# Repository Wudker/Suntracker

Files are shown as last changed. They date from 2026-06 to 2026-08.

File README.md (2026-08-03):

# Suntracker – Solar-Tracking Powerbank with MPPT

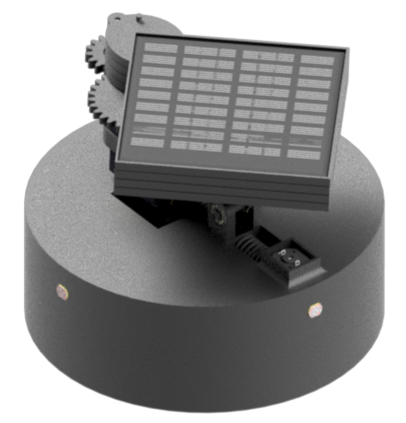
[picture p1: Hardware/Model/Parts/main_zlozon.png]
Suntracker CAD model


Suntracker is a design-stage solar-tracking powerbank developed as a mechatronic student project. It combines dual-axis panel positioning, Li-Ion battery charging, powerbank functionality and a simplified P&O-based MPPT concept. Photoresistors guide the automatic search for the optimal panel position, while the INA219 monitors photovoltaic voltage and current. An STM32 microcontroller controls the positioning mechanism, power rails and charging current through a digital potentiometer. The repository contains firmware, PCB and mechanical files, simulations, a BOM, documentation and validation calculations.

## Technologies

`STM32L051C8` `C/C++` `Photovoltaics` `P&O MPPT` `INA219` `MCP40xx` `TP4056` `XL4015` `DRV8833` `Li-Ion battery` `KiCad` `LTspice` `3D printing`

## Usage and development status

After assembling the device, program the microcontroller using an ST-Link and verify the battery polarity, charging current and mechanical movement limits before operation. The controller searches for the strongest light direction, positions the panel and adjusts the charging current according to the measured photovoltaic power. The project is currently a complete design and documentation package supported by approximate mechanical and energy calculations. The next step is to build a physical prototype and verify tracking efficiency, energy balance and long-term outdoor reliability.

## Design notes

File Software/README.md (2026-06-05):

You need to use ST-Link in order to programm device.

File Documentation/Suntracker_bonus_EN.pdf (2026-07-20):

Suntracker – Instructions | Project Documentation Appendix

## Suntracker

User Manual and Commissioning/Service Instructions

Author: | Bartłomiej Dusza
Student ID: | 274546
Date: | June 17, 2026
Status: | short appendix to the project documentation

This document supplements the project documentation with two missing sections: the user manual and the commissioning/service instructions. It does not replace the main documentation, schematics, PCB files, source code, BOM, simulations or test results.

### 1 Scope and Intended Use

Suntracker is a prototype autonomous solar tracker with a solar powerbank function and a simplified MPPT algorithm. The device positions the panel toward more favorable lighting, measures panel parameters, controls the actuators and reduces energy consumption by entering sleep mode.
The prototype is intended for educational and validation purposes. It is not a finished device designed for long-term, unattended outdoor operation and is not protected against moisture.

### 2 User Manual

### 2.1 Safety Rules

- Do not operate the prototype in rain, at high humidity or on a conductive surface.
- Do not touch the mechanism while the motors are moving, and do not block the panel by hand.
- Do not use the system if the cell is swollen, hot, mechanically damaged or has damaged insulation.
- Do not short-circuit the cell output, panels, 5 V line or 3.3 V line.
- Perform the first powerbank function tests with a test load, not an expensive device.

### 2.2 Preparation for Operation

1. Place the device on a stable surface with enough space for the panel to move freely.
2. Make sure that the wires do not enter the working area of the arm, lead screw or servo.
3. Point the panel toward the light or place a light source in front of the device.
4. Before connecting a USB load, use a multimeter to verify that the output voltage is approximately 5 V.

### 2.3 Startup and Normal Operation

1. Press the POWER_ON power/wake-up button.
2. After startup, the system should activate the required power sections and begin the panel unfolding or positioning sequence.
3. In Harvest_update mode, the device searches for a more favorable panel position using the photoresistors and power measurement.
4. In Harvest mode, the system keeps the panel in its operating position and performs MPPT adjustments.
5. Under low-light conditions, the system may limit movement and enter a power-saving mode.

Correct operation means short, controlled movements of the mechanism, no microcontroller resets, and no noticeable heating of the wires, drivers or converters.

### 2.4 Shutdown, Folding and Storage

1. Press the power button.
2. Wait for the mechanism to complete the folding movement.
3. Do not disconnect the cell while the motors are moving unless an emergency occurs.

### 2.5 Emergency Conditions

Stop the test immediately if smoke, the smell of overheated electronics, excessive cell heating, continuous system resets, a blocked mechanism, sparking, or a significant deviation of the 5 V or 3.3 V rail from its nominal value occurs.

1/2

Suntracker – Instructions | Project Documentation Appendix

### 3 Commissioning and Service Instructions

### 3.1 Required Tools

Multimeter | checking for short circuits, polarity, and the 3.3 V, 5 V, cell and panel voltages.
Laboratory power sup- ply | first power-up with current limiting.
ST-Link / SWD | programming the STM32L0 microcontroller.
Computer with an IDE | compiling and uploading the source code.
Lamp / light source | testing the photoresistors and tracking algorithm.
Test load | testing the 5 V output and powerbank function.

### 3.2 Inspection Before First Power-Up

1. Compare the assembled PCB with the BOM and schematic.
2. Check the polarity of the cell, panels, diodes and electrolytic capacitors.
3. Measure the resistance between VBAT–GND, 5V–GND, 3V3–GND and PANEL+–PANEL-. There should be no short circuit.
4. Check that the mechanism moves freely within its intended range.
5. Check for collisions between PCB components and the motor, lead screw, servo and arm.

### 3.3 First Electronics Startup

1. Disconnect the motors, servo and USB load.
2. Connect power using a laboratory power supply with current limiting, or use a tested 1S cell.
3. Check the stability of the 3.3 V rail. Then check the 5 V rail if it is active.
4. Check that the microcontroller is not resetting repeatedly.
5. Use a debugger to verify I2C communication with the INA219 and MCP40xx devices.

### 3.4 Microcontroller Programming

1. Connect GND, SWDIO, SWCLK and, optionally, NRST from the ST-Link programmer.
2. Select the board/microcontroller variant that matches the STM32L0 used in the device.
3. Make sure that the environment contains the required libraries: STM32, Wire/I2C, timers, STM32LowPower, STM32RTC, INA219 and MCP40xx.
4. Compile and upload the firmware. After uploading, reset the system and check its response to the POWER_ON button.

### 3.5 Actuator and Sensor Startup

Connect the actuators in stages. First test one DC motor in both directions, then the second motor, followed by the servo over a limited range. If the direction of movement is opposite to the expected direction, swap the motor wires or reverse the logic in the control function.
Test the photoresistors under uniform illumination and by covering the sensors one at a time. Illuminating one side should change the indicated direction. If the directions are shifted, correct the pin mapping or the description of the sensor orientation.

### 3.6 MPPT and Sleep Mode Test

For the MPPT test, check the voltage and current readings from the INA219 and the system response to changes in illumination or load. Changing the MCP40xx setting should affect the operating conditions of the charging circuit. If the algorithm oscillates too much, reduce the adjustment step or increase the measurement settling time.
For sleep mode, confirm that the System_Sleep() function switches off unnecessary power sections, places the H-bridge inputs in a safe state and allows the system to wake using the button. After changes to interrupt handling, perform several cycles: startup – operation – sleep – wake-up.

2/2

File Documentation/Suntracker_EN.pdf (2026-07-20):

# Suntracker Project

Final Documentation of a Theoretical Project

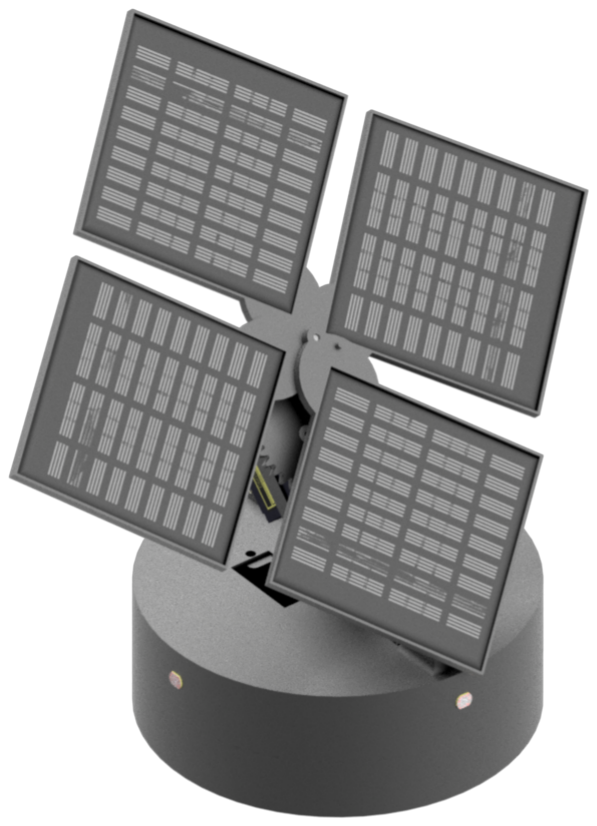
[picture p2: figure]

Author | Bartłomiej Dusza, Eng.
Date | June 17, 2026
Supervisor | Krzysztof Kwoka, Ph.D., Eng.

This document summarizes the project completed for the “Electronic Systems in Mechatronics” course.

# Contents

1 Project Objective and Assumptions | 2
2 Electronics | 3
3 Mechanical Design | 13
4 Software | 18
5 Validation | 21
6 Final Conclusions | 30
7 References | 32

# 1 Project Objective and Assumptions

The objective of the project is to design a prototype energy storage system powered by photovoltaic panels. The device is intended to operate as a small autonomous energy source capable of charging a Li-Ion cell and powering a load through a 5 V section. Unlike simple fixed solar systems, the proposed device includes a mechanism that positions the panels relative to the direction of incoming light. This solution is intended to extend the effective exposure time of the panels and increase the amount of energy that can be harvested during the day.

Existing solutions of this type can be divided into several groups. The simplest photovoltaic systems use panels mounted at a fixed angle. Such a solution is inexpensive, simple and reliable, but it cannot actively adjust the panel position to the current position of the sun. More advanced designs use single-axis or dual-axis solar trackers that change the panel position during operation. Single-axis trackers most often follow the sun from east to west, while dual-axis trackers also allow the tilt angle to be corrected. This can increase the potential energy yield, but it also makes the mechanical design and control electronics more complex and worsens the energy balance because the actuators require power.

The proposed prototype uses an intermediate approach. Its purpose is not to maximize power at any cost, but to evaluate whether a small self-sufficient solar system is practical. The key assumption is a positive energy balance: the energy used for control, measurements and panel positioning should be lower than the additional energy obtained through improved panel positioning. For this reason, the system should operate periodically, remain in a low-power mode most of the time, and activate the actuators only when the panel position must be changed.

The design uses four small photovoltaic panels connected in series, a panel voltage and current measurement circuit, a DC/DC converter, a cell charging and protection circuit, and a microcontroller supervising the complete system. The system should measure the current power generated by the panels, adjust the operating point using a simplified pseudo-MPPT algorithm, and control the actuators responsible for positioning the structure. Safe charging of the Li-Ion cell and disconnection of actuators when they are not required are also important design requirements.

The scope of the project includes creating a prototype model, designing the power and control paths, preparing a mechanical structure that allows the panel position to be changed, and developing basic control software. The project is theoretical in nature.

# 2 Electronics

The system block diagram presents the general structure of the device’s power, measurement and control paths. The photovoltaic panels are the energy source, and their voltage and current are measured to determine the current power supplied by the system. The energy is then transferred to the DC/DC converter and the BMS section responsible for charging and protecting the cell, which acts as the energy storage device. Separate voltage sections are supplied from the cell: 3.3 V for the logic and 5 V for the actuators, mainly the motors. The microcontroller is the central control unit. Based on the measured data, it supervises the pseudo-MPPT operation and controls the H-bridge responsible for positioning the panels.

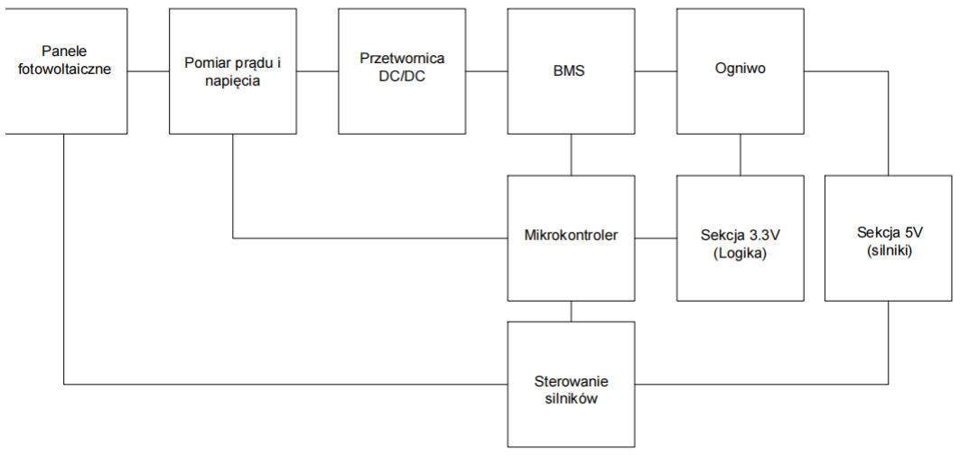
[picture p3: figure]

Figure 2.1: System block diagram.

## 2.1 Photovoltaic Panels

The power source is one of the most important parts of the system. Photovoltaic panels are nonlinear power sources that use the internal photoelectric effect. Because of this nonlinear behavior, maximum power point tracking (MPPT) is required to obtain the highest possible power. The main idea is to select the current drawn from the panel so that the system receives the maximum available power.

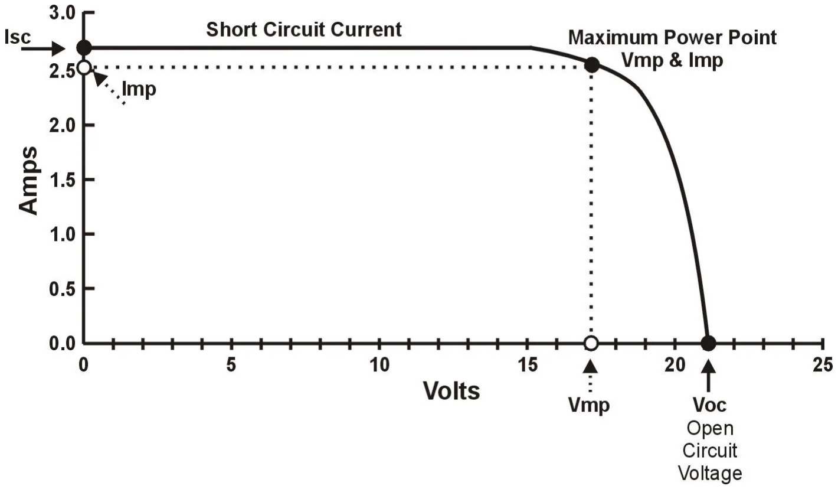
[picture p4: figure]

Figure 2.2: Panel current as a function of voltage [1].

Control of such a panel is based on reading its current voltage and current and then driving the DC/DC converter connected to the panel input. Photovoltaic panels can be connected in series to add their voltages, in parallel to add their currents, or in a mixed configuration. The project uses four identical panels, each with a nominal voltage of 5.5 V and a power rating of 0.4 W, connected in series. This configuration was selected to reduce transmission losses caused by the resistance of the wires. When connected in series, the panels provide a nominal voltage of approximately 22 V and a total power of 1.6 W. This provides enough voltage margin for the converter to operate under lower light levels. The disadvantage of this configuration is its sensitivity to differences in illumination between individual panels. If one panel is poorly illuminated, it may significantly limit the entire string. An alternative solution would be to connect two panels in series as one pair and then connect two such pairs in parallel, producing approximately 11 V at the output. The disadvantage is that current may flow from the better-illuminated pair to the less-illuminated pair. Schottky diodes can prevent this reverse current, but they introduce a voltage drop and additional power losses. With a series connection, bypass diodes may also be connected in parallel with the individual panels. They allow current to bypass a shaded panel or one that temporarily produces much less power than the others. As a result, one poorly illuminated panel does not block the complete string, although the total voltage is reduced. This improves resistance to partial shading, but increases the component count and introduces additional diode losses. All four panels could also be connected in parallel. In this case, the output voltage would remain approximately 5.5 V, while the nominal current would increase to approximately 0.29 A and the total power would remain approximately 1.6 W. This configuration would be more resistant to partial shading of one panel. However, such a low voltage would make it difficult to use a step-down converter and would most likely require a step-up converter. In practice, this option would be less suitable for the selected power architecture because it would produce higher wire currents and greater conduction losses.

## 2.2 Power Conversion

This section is divided into the converter used to implement pseudo-MPPT and the converters that generate the voltage rails required by the individual components from the battery voltage.

The converter section can be implemented in three main ways. The first is a custom discrete converter built from basic power-electronic components such as an inductor, diode, MOSFET and control circuit. The second approach is to use a ready-made DC/DC converter controller. The third option is a more highly integrated circuit that controls the converter and also provides additional functions such as MPPT and cell charging control.

For the proposed system, the main selection criteria were implementation complexity, ease of commissioning under prototype conditions, availability of documentation, and suitability for a photovoltaic-powered device. Table 2.1 compares the considered options.

Table 2.1: Comparison of converter section implementations

Solution | Advantages | Limitations | Assessment
Custom discrete converter | Very high design flexi-bility, component selec-tion matched precisely to system requirements, and potentially high effi-ciency. | Highest design com-plexity, including the need to solve control, feedback, stability and power-component se-lection issues. | The most flexible solution, but too complex for the pro-totype stage
XL4015 [2] | Simpler implementa-tion, sufficient voltage and current ratings, and basic built-in pro-tection mechanisms. | Less flexible than a dis-crete solution and no native MPPT function. | The most practical choice for the pro-totype
BQ25750 [3, 4] | High level of integration, MPPT support and Li-Ion cell charging func-tions. | Greater application complexity, more dif-ficult implementation and stricter require-ments for the design of the complete power section. | The most function-ally advanced solu-tion

Considering the prototype nature of the device and the need to limit system complexity, the XL4015 was selected as the most reasonable solution [2]. Compared with the BQ25750, it is easier to implement and commission while providing sufficient parameters for the proposed system. However, the XL4015 does not provide native MPPT. This function must therefore be implemented externally, and the required cell charging profile must be handled separately.

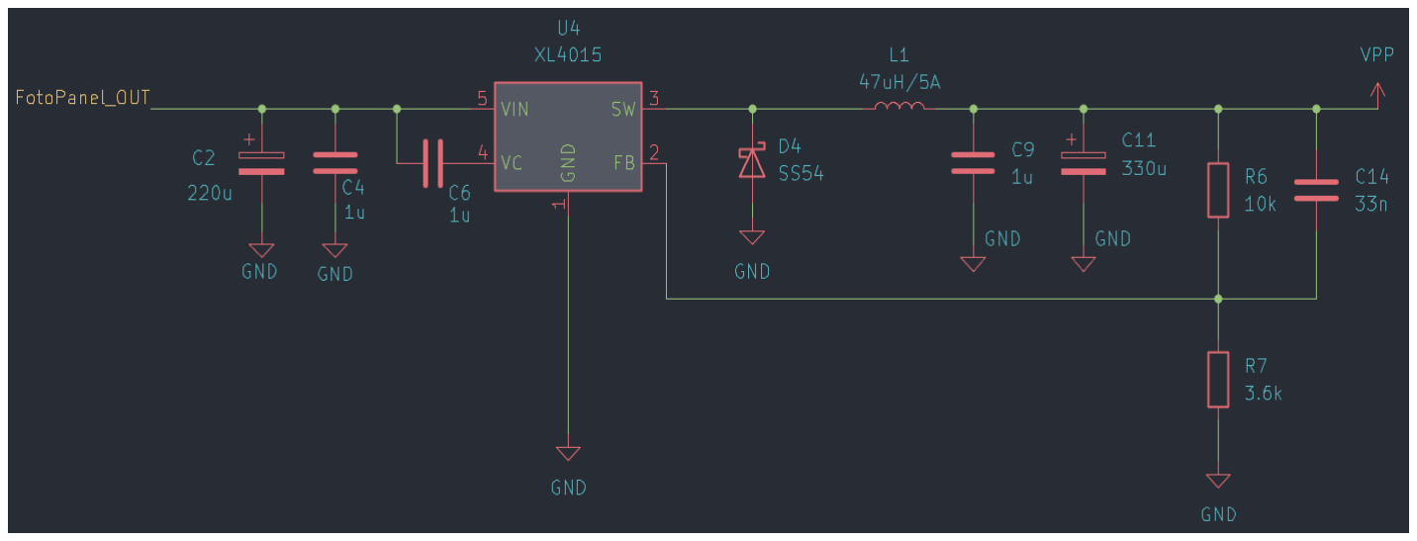
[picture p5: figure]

Figure 2.3: Converter circuit diagram.

The second section contains two converters: one supplies the 3.3 V rail and the other supplies the 5 V rail. The 3.3 V section uses the MCP1825S33. Its low dropout voltage is an important parameter because the regulator is powered directly from the battery. A power-path circuit is also used to switch the supply of this section automatically between the battery and the panels.

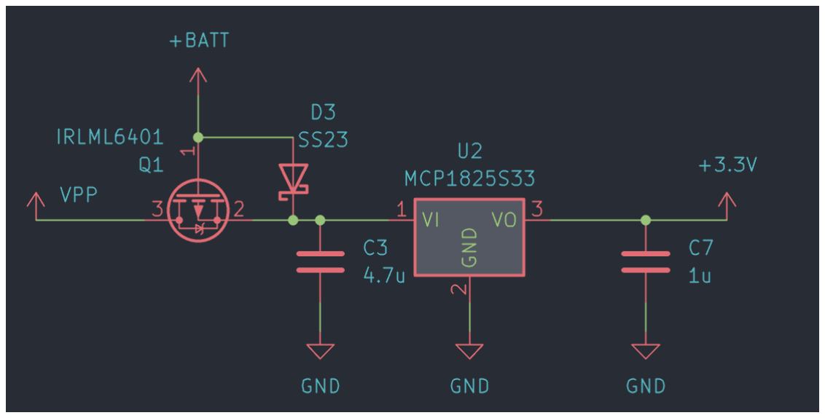
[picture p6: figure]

Figure 2.4: 3.3 V converter circuit diagram.

The second converter is based on the TPS61022, for which a low input voltage is also an important parameter. Another visible difference is the large number of capacitors. Their placement follows both the manufacturer’s documentation and the needs of the system, because this section mainly powers the motors and supplies the device connected to the USB output. The capacitors are required because the DC motors and servos draw high currents during operation and introduce significant noise into these power lines.

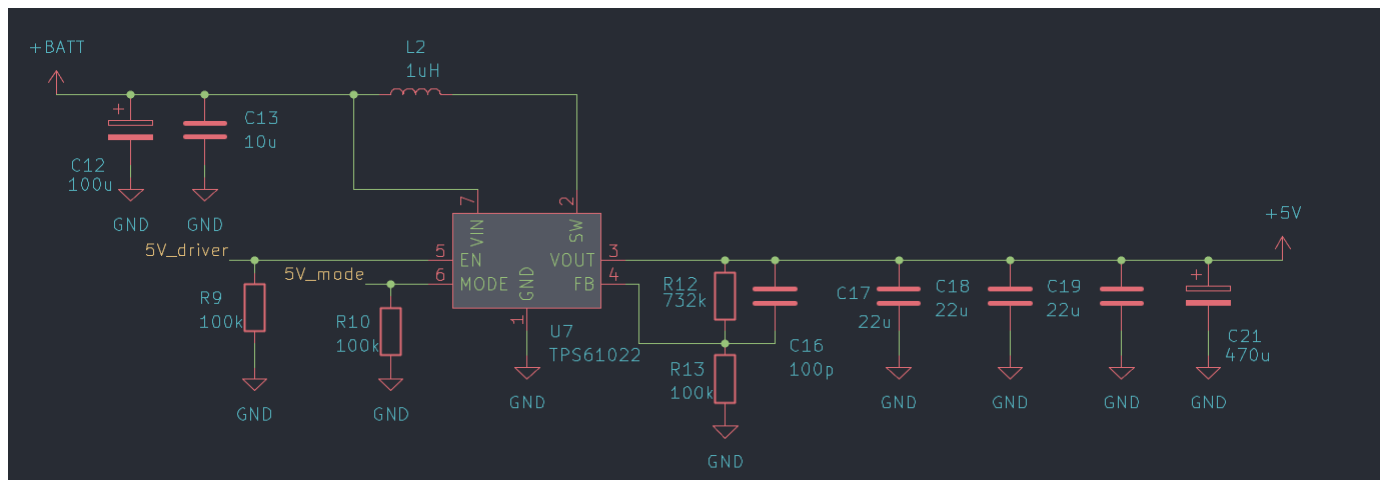
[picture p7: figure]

Figure 2.5: 5 V converter circuit diagram.

## 2.3 Microcontroller

Four representative solutions were analyzed during microcontroller selection: STM32L0, AVR128DB, ESP32-C6 and RP2040. The main requirements of the proposed system were low power consumption in sleep modes, reasonable consumption during active operation, peripherals required for energy measurement and actuator control, operation from a 3.3 V supply, and sufficient program memory.

Table 2.2: Comparison of selected microcontroller families for the proposed system

Family | Advantages | Limitations | Assessment
STM32L0 [5] | Very low power con-sumption in low-power modes, RTC and I2C/SPI/USART inter-faces. | No native wireless con-nectivity and more com-plex configuration than simple 8-bit devices. | The best choice for the prototype
AVR128DB [6] | Very low standby power consumption, simple ar-chitecture and Sleep-Walking. | Lower performance, less memory and fewer func-tions than modern 32-bit devices. | A good option for a simplified ver-sion
ESP32-C6 [7] | Native Wi-Fi 6, Bluetooth LE, remote configuration and very low deep-sleep current. | High current during op-eration and transmission, which worsens the en-ergy balance of the solar system. | Reasonable only when connectivity is required
RP2040 [8, 9] | High flexibility, two Cortex-M0+ cores, 264 kB SRAM and PIO. | Requires external QSPI memory and has unfa-vorable standby power consumption. | The least suitable choice for this project

The STM32L051C8 from the STM32L0 family was selected as the most suitable microcontroller for the prototype. It combines low power consumption with enough peripherals for the project, including an ADC, an I²C interface for communication with the INA219, timers, an RTC, and digital outputs for controlling power sections and actuators. Compared with the STM32L4 family, the selected device offers lower performance and less memory. However, low power consumption, a simpler device structure, and sufficient functionality for the solar tracking and pseudo-MPPT algorithms were more important in this project. The AVR128DB family also has low power consumption, but it is less flexible than a 32-bit STM32 microcontroller [6]. The ESP32-C6 is an attractive solution when native wireless connectivity is required, but the high operating and peak currents of its radio make it less suitable from the energy-balance perspective [7]. The RP2040 is the least suitable device for a solar-battery application with long standby periods. The manufacturer specifies a current of approximately 180 µA even in deep sleep and recommends fully disconnecting the power supply in applications that require minimum standby current [8, 9].

The microcontroller section is based on the STM32L051C8Tx, which is the main control unit of the complete system. Programming and service connectors provide access to SWDIO, SWCLK, NRST and BOOT0. This allows the device to be programmed and debugged without removing the microcontroller from the PCB. NRST is pulled up to 3.3 V with a 10 kΩ resistor, while BOOT0 is pulled down to ground with a 10 kΩ resistor. As a result, the microcontroller starts the program from Flash memory after a reset. Power filtering is also an important part of this section. The supply lines use 100 nF decoupling capacitors and larger capacitors to reduce noise and temporary voltage drops during operation. The analog supply is additionally separated with a ferrite bead, which improves the resistance of ADC measurements to noise generated by the actuators and converters.

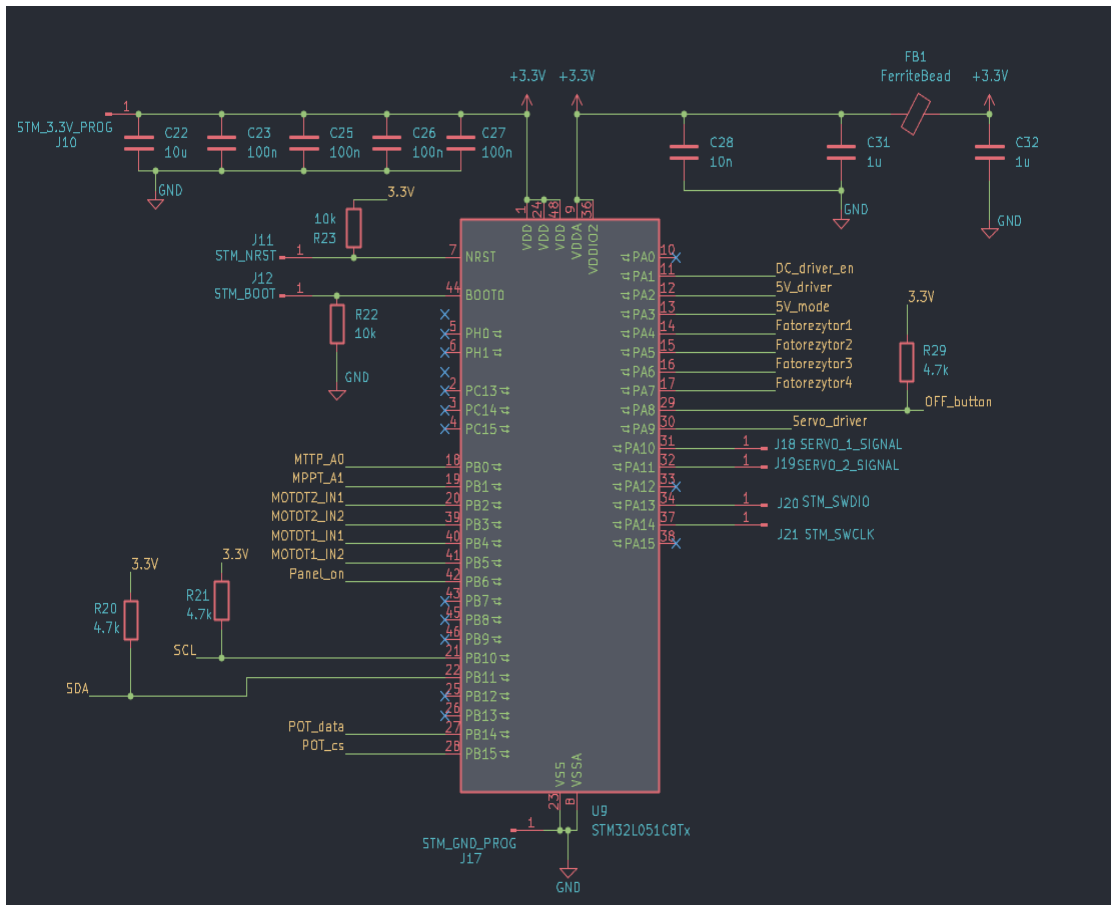
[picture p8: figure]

Figure 2.6: Microcontroller circuit diagram.

The microcontroller pins are divided by function according to the tasks performed by the system. PA0-PA3 control the power sections, including the motor driver enable, the 5 V supply and the converter operating mode. PA4-PA7 are analog inputs used to read the four photoresistors, which determine the direction of panel position correction. PB0 and PB1 are used for MPPT-related measurements, while PB2-PB5 control the direction of the DC motors. PB6 enables the panel section, and PB10 and PB11 form the I²C bus used, among other functions, to communicate with the INA219. PB14 and PB15 control the digital potentiometer used to adjust the pseudo-MPPT operating point.

## 2.4 Modules

### 2.4.1 Battery Management System (BMS)

The battery charging and protection section is based on the TP4056 and the DW01A protection circuit working with a dual MOSFET. The TP4056 charges a single Li-Ion cell, while the programming resistor sets the maximum charging current. LEDs indicate the charger status, including charging in progress and charge completion. The DW01A and MOSFETs protect the cell against over-discharge, overcharge and excessive current, allowing the battery to be used safely as the system’s energy storage device.

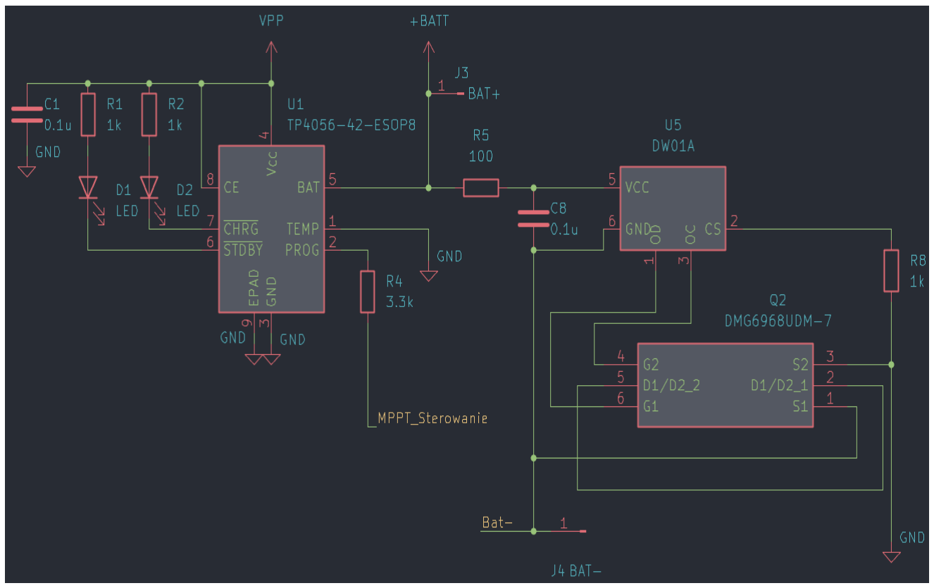
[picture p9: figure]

Figure 2.7: Cell charging and protection circuit diagram.

### 2.4.2 Operating Point Control

The design uses an MCP4021-5k digital potentiometer to adjust the operating point of the pseudo-MPPT circuit. The microcontroller controls the potentiometer through the POT_data and POT_cs lines and changes its resistance according to the currently measured panel power. The potentiometer wiper is connected to the MPPT_Sterowanie line, which affects the operating conditions of the power conversion section. This solution allows the load seen by the panels to be changed in software without a more complex MPPT controller.

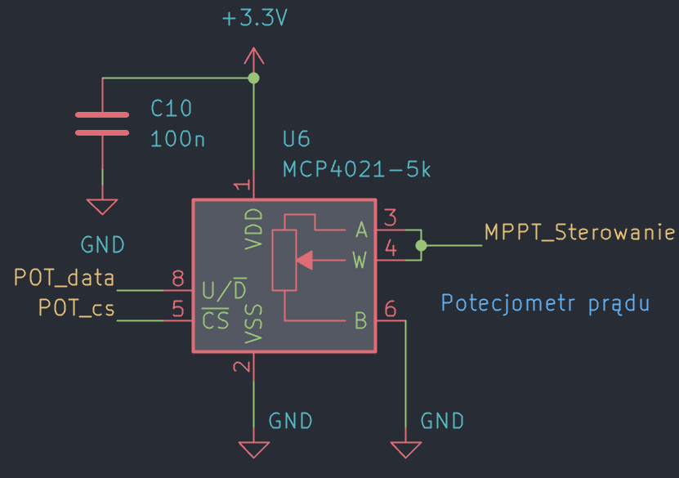
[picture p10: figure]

Figure 2.8: Digital potentiometer circuit diagram.

### 2.4.3 Panel Voltage and Current Measurement

The INA219AxD is used to measure the electrical parameters of the photovoltaic panels. The sensor measures the voltage drop across a shunt resistor in the panel power path, which allows the current drawn from the panels to be determined. It also measures the bus voltage, allowing the microcontroller to calculate the current power generated by the panels. Communication with the microcontroller uses the I²C bus, and a capacitor placed at the supply pin filters the power supply.

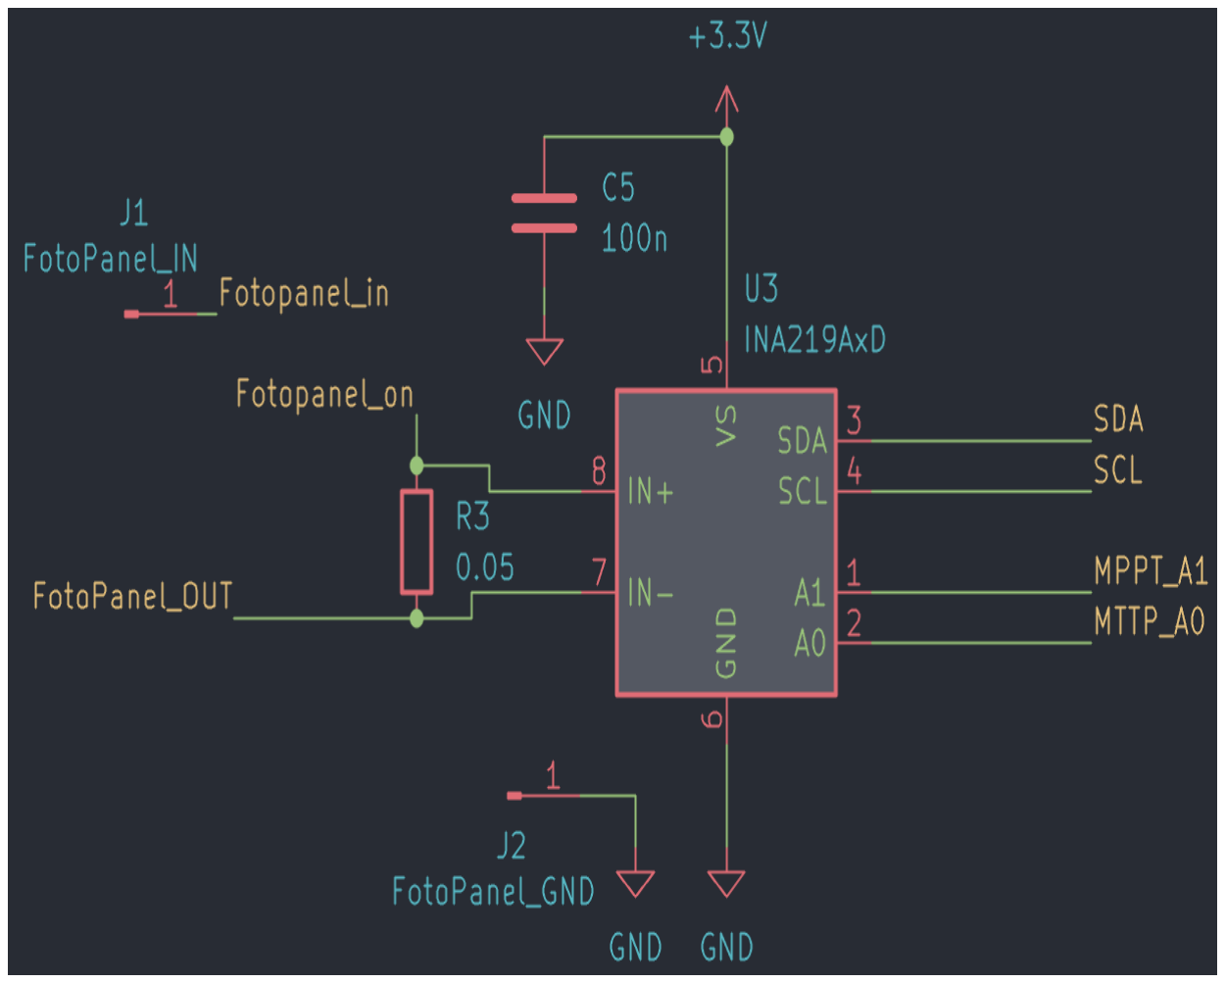
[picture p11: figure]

Figure 2.9: Power sensor circuit diagram.

### 2.4.4 Motor Control

The DC motor control section is based on the DRV8833PW dual H-bridge. It provides independent control of two motors through the MOTOT1_IN1, MOTOT1_IN2, MO-TOT2_IN1 and MOTOT2_IN2 signals generated by the microcontroller. The DC_driver_en line enables the driver or puts it into sleep mode, reducing current consumption when the actuators are not in use. Low-value shunt resistors in the motor paths are used to limit and observe actuator current, while supply capacitors reduce the effect of noise generated by the motors. Because of the power dissipated in the shunt resistors, components rated for at least 0.5 W should be used in these positions.

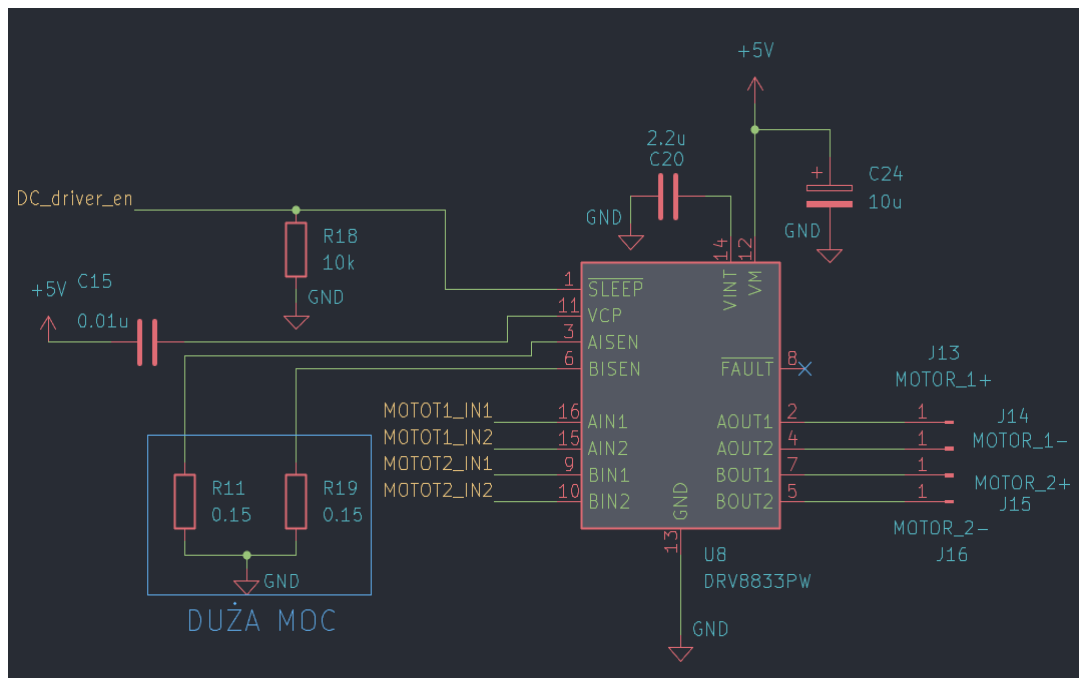
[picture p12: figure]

Figure 2.10: H-bridge circuit diagram.

R11 and R19 operate as current-sense shunts in the DC motor paths. Despite their low resistance, noticeable power may be dissipated in them during motor startup. They therefore require a higher power rating than typical signal resistors. The relationship P = I

2R means that even a short current increase significantly raises the thermal load on these components. The design also disconnects the servo supply with a simple high-side switch, so the servos do not draw current in sleep mode or when no movement is required.

# 3 Mechanical Design

The mechanical part of the project is a prototype structure that positions the photovoltaic panels relative to the light source and houses the main electronic components. The structure can be divided into two main parts: a base containing the electronics and drive section, and a moving fan-shaped panel assembly. This combines the enclosure, positioning mechanism and photovoltaic panel support in one compact structure.

The mechanical design is a prototype, so the main goals were to verify the concept, component placement and possible panel movement. The CAD model includes space for the PCB, motors, servo, transmission components, wiring and mounting points. Additional visualizations were prepared to assess component placement and potential collisions between moving parts.

## 3.1 Base

The base is designed as a cylindrical enclosure that supports the complete structure, protects the electronics and provides space for the drive components. It contains the PCB, power components, wires and part of the mechanism that rotates the panel assembly. The round shape suits the device because the structure can rotate relative to its surroundings and has no single fixed orientation.

The upper part of the base contains the PCB with the control and power circuits. The board is mounted on spacers to keep it away from the enclosure surface and reduce the risk of a short circuit. The PCB placement leaves space for wiring to the photovoltaic panels, motors, servos and external components such as the power button.

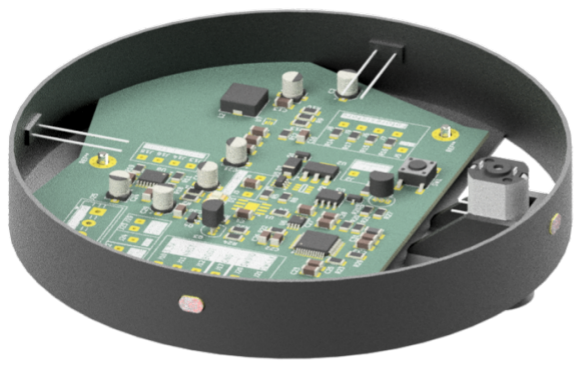
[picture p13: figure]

Figure 3.1: Interior of the base showing the PCB placement.

The enclosure also includes access and mounting holes. They allow user-accessible components to be placed outside, components to be installed, and the individual parts of the base to be joined. Clearance between the electronics and mechanical components is important so that movement of the transmission and shaft does not interfere with the PCB or wires. The final physical assembly is intended to use suitable heat-set threaded inserts.

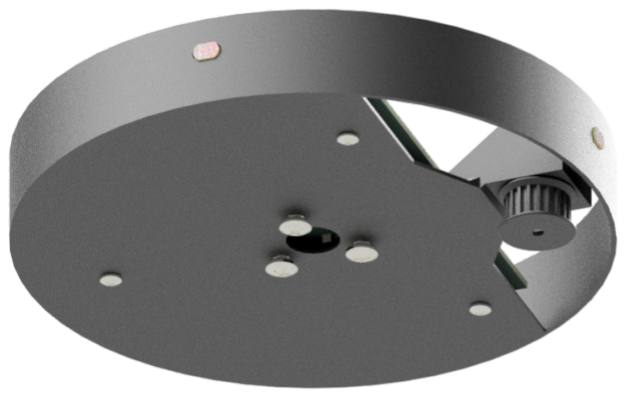
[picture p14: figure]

Figure 3.2: Lower side of the base and the space intended for mechanical components.

The base contains a mechanism that transfers motion to the main shaft. A transmission reduces the required motor torque and provides slower, more controlled movement. This is useful because a solar tracker does not require high rotational speed, but stable and repeatable panel positioning relative to the light source.

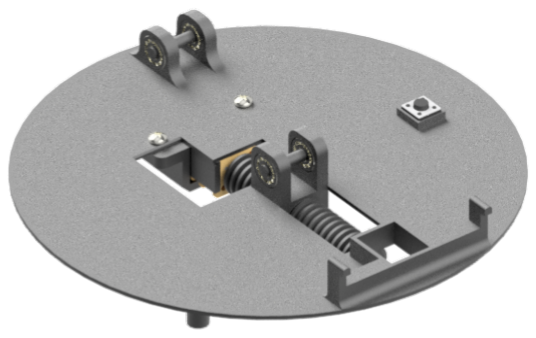
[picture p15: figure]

Figure 3.3: Upper part of the base with the drive mechanism components.

The drive section is placed below the upper plate of the base. This separates the electronics from moving mechanical components and makes better use of the available space inside the enclosure. The model includes space for the motor, a belt transmission using a standard GT2 belt, and guiding components that transfer motion to the main axis of rotation.

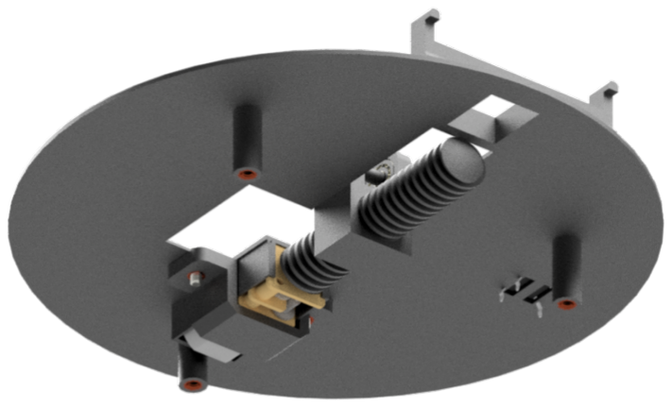
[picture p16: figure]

Figure 3.4: Drive mechanism viewed from the lower side of the base.

The lower part of the base closes the enclosure and provides space for the battery cells. The cells should be installed before the mechanism is assembled completely. The assembly order is important because access to the inside of the base becomes much more difficult after the gear has been installed on the main shaft.

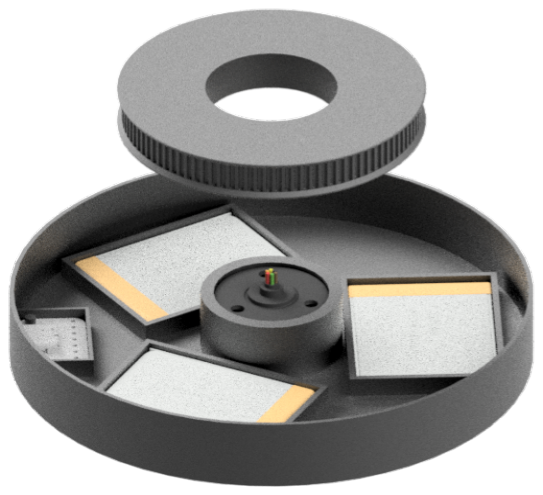
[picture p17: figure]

Figure 3.5: Lower part of the base with space for the cells and the main-shaft gear.

The gear on the main shaft transfers torque from the drive mechanism to the rotating upper part of the structure. In the planned assembly sequence, the cells and power wires are installed first, followed by the gear on the main shaft. In the final design, this component may use a tight fit on the shaft or be secured with adhesive to reduce the risk of slipping during operation.

The selected base design combines an electronics enclosure, cell mounting space and a support for the rotation mechanism. The main limitation of this version is difficult service access after complete assembly, which makes the assembly sequence important. A future version could use an easier-to-remove gear mounting method or a separate service cover that provides access to the cells without disassembling the mechanism.

## 3.2 Fan Assembly

The moving part of the device is a fan-shaped assembly consisting of four photovoltaic panels. The panels are arranged around a central mounting point, which increases the active surface area while keeping the structure compact. Compared with one large panel, this solution is more convenient for a prototype because it makes the panels easier to arrange and integrate with the folding mechanism.

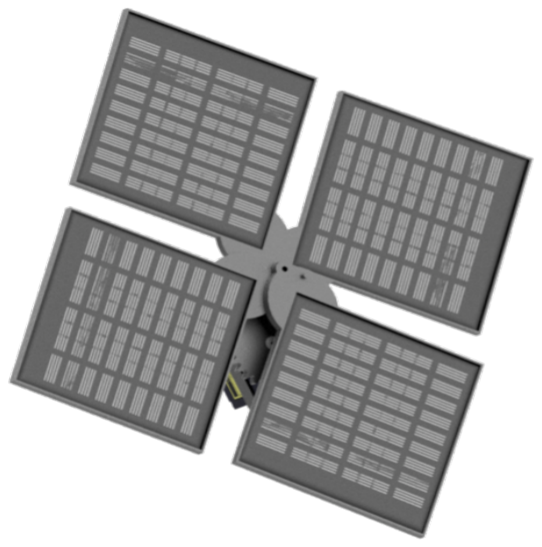
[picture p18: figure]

Figure 3.6: Moving assembly with four photovoltaic panels.

The panels are attached to a central mechanism that changes their position relative to the base. Its purpose is to place the panels at a more favorable angle to the light source.

The design uses a servo and a transmission that increases the useful range of motion. This allows the panel position to be controlled with a simple actuator.

The central panel mounting keeps the load relatively symmetrical. This is important because uneven mass distribution could increase the required actuator torque and load on the transmission. The model also provides space to route wires from the panels to the electronics in the base.

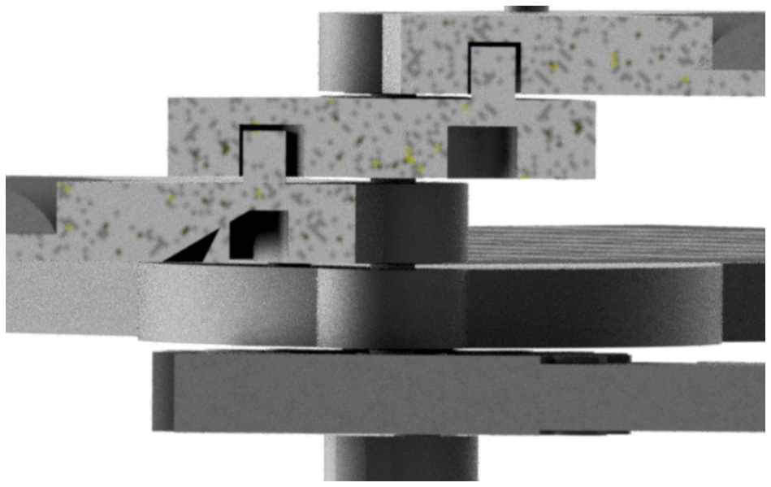
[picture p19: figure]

Figure 3.7: Close-up of the panel positioning mechanism.

Potential collisions between moving components were also checked during the design process. Particular attention was paid to the central joint, the transmission and the points where the panels pass the edges of the base. This verification is important because even a small displacement in a folding mechanism may limit the range of motion or block the structure. The movement of each fan segment is based on a round pin in the lower segment. Through a form-fit connection, the pin moves inside a channel in the upper segment.

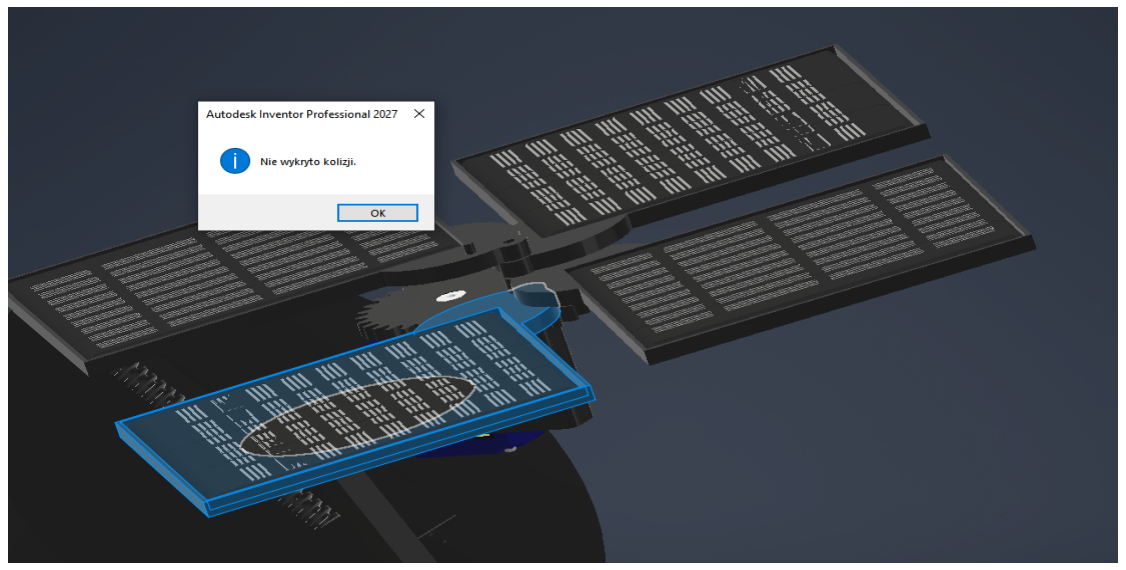
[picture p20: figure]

Figure 3.8: Analysis of the working space and potential collisions between moving components.

# 4 Software

## 4.1 Program Structure

The software is divided into modules corresponding to the main hardware blocks. The main file initializes the system and handles the state machine, while the remaining modules provide power measurement, actuator control, photoresistor and digital potentiometer support, and low-power modes. This structure simplifies software development and separates system control logic from functions that directly handle electronic components. The program was developed using the PlatformIO extension for Visual Studio Code. Because of the prototype nature of the project, the Arduino framework was used. For a final device, it would be more suitable to rewrite the code using a framework closer to the STM32 architecture.

The program operates cyclically, but it does not perform all measurements and movements continuously. Because the device is solar-powered, reducing the active time of the microcontroller and actuators was a priority. A state machine is therefore used to run individual functions only when they are required.

Table 4.1: Program modules

Module | Function
main.cpp | Main program loop and state machine handling.
General.cpp | Startup, sleep, folding and power-section control functions.
MPPT.cpp | Power measurement and panel operating-point control.
Photorezistors.cpp | Photoresistor readings.
Motors.cpp | DC motor and servo control.
Interrupt.cpp | Interrupt, power-button and periodic wake-up handling.

## 4.2 System State Machine

The main program logic is based on a state machine. This provides a clear definition of the current device mode and the actions that should be performed at a given time. The program contains five basic states: START, Harvest_update, Harvest, FOLD and Sleep.

The START state initializes the system after power-up or wake-up. It activates the required power sections, sets the initial mechanism position, performs initial panel positioning and initializes the pseudo-MPPT algorithm. When these operations are complete, the system enters the Harvest state.

Harvest is the main operating state. In this mode, the operating point of the photovoltaic panels is adjusted periodically based on voltage and current measurements. After the update, the system enters sleep mode to reduce energy consumption.

The Harvest_update state repositions the panels according to the current direction of incoming light. It is entered periodically after a specified number of sleep cycles. In this state, the system reads the photoresistors again, corrects the panel position and updates the operating point.

The FOLD state folds the mechanism. It is entered when the system is switched off with the button. After the panels have been folded, the device enters sleep mode.

Sleep is the low-power state. Unnecessary power sections, including the motors and servos, are disconnected, and the microcontroller enters deep sleep. The system wakes after a specified time or when the button is pressed.

Table 4.2: Program operating states

State | Operation
START | System startup, power activation, panel positioning and MPPT initialization.
Harvest | Panel power measurement and pseudo-MPPT operating-point update.
Harvest_update | Periodic panel position correction toward the strongest illumina-tion.
FOLD | Mechanism folding after the system is switched off.
Sleep | Low-power mode, actuator disconnection and microcontroller sleep.

## 4.3 Sun Position Tracking Algorithm

Four photoresistors are arranged so that illumination levels on different sides of the panel can be compared to determine the direction of the strongest light. The program takes several measurements from each photoresistor and calculates an average value, reducing the effect of noise and individual incorrect readings.

The direction in which the panel should rotate is determined from the differences between the readings. If the light level is too low or the differences are within the specified dead zone, the position is not corrected. This avoids unnecessary motor operation when a change in position would not provide a noticeable improvement.

After the initial position correction, additional fine adjustment is performed. The system makes small steps in one direction and compares the panel voltage before and after each movement. If the voltage increases, movement continues. If the result becomes worse, the mechanism reverses the last step. This allows a more favorable panel position to be found without complex astronomical calculations.

## 4.4 Pseudo-MPPT Algorithm

The project uses a simplified maximum power point tracking algorithm. The microcontroller reads the panel voltage and current with the INA219 and uses these values to calculate the current power generated by the panels. The operating point is adjusted by changing the resistance of the digital potentiometer, which affects the operating conditions of the power conversion section. The algorithm uses the perturb-and-observe method. After each resistance change, the current panel power is compared with the power measured in the previous step. If the power has increased, the adjustment continues in the same direction. If the power has decreased, the adjustment direction is reversed. Minimum and maximum resistance limits prevent operation outside the accepted range. If the panel voltage falls below a defined threshold, the algorithm increases the resistance and reduces the load on the panels. This prevents excessive loading of the photovoltaic source under low-light conditions.

## 4.5 Actuator Control

The panel positioning mechanism uses DC motors and servos. The DC motors are controlled by a dual H-bridge that allows the direction of rotation to be changed and the drive to be stopped. The program determines the motor operating time from the requested displacement or angle and then activates the appropriate control outputs.

To reduce sudden current changes, the motor does not operate continuously with one drive value. Movement is divided into acceleration, higher-speed operation and deceleration stages. This reduces mechanism jerking and limits overloads during panel positioning.

The servos position selected parts of the mechanism. Their power can be disconnected when they are not in use, reducing current consumption in standby mode and during operation when their position does not need to change.

## 4.6 Power Management and Sleep Mode

Because the photovoltaic panels provide limited power, energy management is an important part of the program. The system does not remain active continuously. After measurements, MPPT adjustment or position correction, it enters sleep mode. Before entering sleep, it switches off the power sections for the motors, servos and selected 5 V logic components.

The system can wake periodically after a specified time or when the power button is pressed. The button has two functions: it starts the system when it is off and begins the mechanism folding procedure when the system is active. This event is handled with an interrupt.

Sleep mode reduces the average current consumption of the device. This is especially important because the energy used by the microcontroller and actuators should not exceed the additional energy obtained through improved panel positioning.

# 5 Validation

## 5.1 Energy Balance Verification

Because the project is theoretical and prototype-oriented, energy validation was performed using approximate calculations. The purpose of this section is to verify whether the selected system architecture can operate as a self-sufficient energy source and charge the selected Li-Ion cell pack. The project uses four photovoltaic panels, each with a nominal voltage of 5.5 V and a power rating of 0.4 W. When connected in series, they provide a nominal voltage of approximately 22 V and a total power of:

PP V = 4 · 0, 4 W = 1, 6 W

This is the maximum power available under favorable lighting conditions. In practice, losses in the DC/DC converter, charging circuit, wires and protection components must be considered. Assuming an XL4015 converter efficiency of approximately 85% and an efficiency of approximately 75% for the remaining charging path, the power that can be delivered to the cell pack can be estimated as:

PCHG = 1, 6 W · 0, 85 · 0, 75 ≈ 1, 02 W

The project uses three 450 mAh Li-Ion cells connected in parallel. This gives a 1S3P pack with a total capacity of:

CBAT = 3 · 450 mAh = 1350 mAh = 1, 35 Ah

With a nominal Li-Ion cell voltage of approximately 3.7 V, the energy stored in such a pack is:

EBAT = 3, 7 V · 1, 35 Ah ≈ 5, 0 W h

With a charging power of approximately 1 W, the theoretical time required to recharge the pack can be estimated as:

tCHG =

5, 0 W h
1, 02 W

≈ 4, 9 h

In practice, this time will be longer because panel power depends on the angle of incoming light, cloud cover, temperature, partial shading and the current operating point. In addition, the final stage of Li-Ion charging uses a decreasing current, so a full charge may take longer than a simple energy-to-power calculation suggests. Nevertheless, the result shows that several hours of good sunlight per day should allow the system to recharge the selected cell pack.

For approximately 1.02 W delivered to the cells, the pack charging current can be estimated as:

ICHG =

1, 02 W
3, 7 V

≈ 0, 28 A

For a 1.35 Ah pack, this corresponds to a charging rate of:

0, 28 A
1, 35 Ah

≈ 0, 21C

This is a low value, which is favorable for the Li-Ion pack. Cells connected in parallel should have similar parameters and a similar state of charge before they are connected to limit equalization currents between them.

The next stage of validation estimates the energy used by the actuators. The DC motors are controlled by the DRV8833. The motor paths contain 0.15 Ω shunt resistors R11 and R19, allowing the H-bridge to limit motor current. For the DRV8833, the current limit threshold is related to the voltage at the xISEN sense input. Assuming a threshold of approximately 0.2 V, the current limit can be estimated as:

ICHOP =

0, 2 V
0, 15 Ω

≈ 1, 33 A

This means that during startup or a temporary mechanism stall, the motor should not draw its full short-circuit current without limitation. This improves system safety, although it also limits the maximum available actuator torque. At an operating current of 0.5 A, the power dissipated in the shunt resistor is:

PR = I

2R = (0, 5 A)

2
- 0, 15 Ω = 0, 0375 W

At the 1.33 A current limit, the instantaneous power increases to:

PRCHOP = (1, 33 A)

2
- 0, 15 Ω ≈ 0, 27 W

These values are acceptable for short periods of operation. However, the temperature of the shunt resistors and H-bridge should be verified in a physical prototype during actual mechanism movement.

The motor that rotates the complete mechanism is a geared motor with a nominal speed of approximately 100 RPM at 6 V. In this project, it operates from 5 V with an additional 6:1 reduction provided by a GT2 belt. Using simplified linear scaling with voltage, its no-load speed at 5 V can be estimated as:

nM1,5V = 100 RPM ·

5
6

≈ 83 RPM

After the 6:1 reduction, this gives an output speed of approximately:

nOUT =

83 RPM
6

≈ 13, 9 RPM

In the software, movement of the rotation motor uses three PWM stages: acceleration, main movement and braking. For PWM values of 120, 240 and 20, the average duty factor is:

kPWM =

120 + 240 + 20
3 · 255

≈ 0, 50

The simplified output speed with this drive pattern is therefore approximately:

nOUT,PWM = 13, 9 RPM · 0, 50 ≈ 6, 9 RPM

This corresponds to an angular speed of approximately 41 degrees per second. An example 90-degree position correction therefore takes approximately:

tM1 =

90◦
41◦/s ≈ 2, 2 s

At an operating current of 0.5 A, the energy used by one correction is:

EM1 = 5 V · 0, 5 A ·

2, 2 s
3600 s/h ≈ 0, 0015 W h

Even with 16 position corrections over several hours of operation, the energy used by the rotation motor is:

EM1day = 16 · 0, 0015 W h ≈ 0, 024 W h

For an overload case in which the current reaches the approximate 1.33 A limit during movement, the energy used by 16 corrections would be approximately:

EM1CHOP = 16 · 5 V · 1, 33 A ·

2, 2 s
3600 s/h ≈ 0, 064 W h

This is still a small value compared with the energy stored in the cell pack, but such a condition should be treated as a short-term fault case and not as normal operation.

The second motor rotates the lead screw and moves the fan support linearly. The selected motor has a rated speed of approximately 410 RPM at 6 V, while the software timing model uses 400 RPM. With a 5 V supply, the actual no-load speed may be closer to:

nM2,5V = 410 RPM ·

5
6

≈ 342 RPM

For a screw lead of 10 mm/rev, this gives a linear speed of:

vLIN =

342
60
- 10 mm ≈ 57 mm/s

An example 20 mm support displacement would therefore take approximately:

tM2 =

20 mm
57 mm/s ≈ 0, 35 s

At an operating current of 0.5 A, the energy used by such a movement is:

EM2 = 5 V · 0, 5 A ·

0, 35 s
3600 s/h ≈ 0, 00024 W h

Even with several support movements, this actuator has a negligible effect on the total energy balance. More important than the movement energy itself is whether the screw and guide mechanism produces excessive resistance. With a motor stall torque of approximately 1.3 kgcm at 6 V, scaled to 5 V, and an assumed screw and guide efficiency of approximately 30%, the short-term linear force can be estimated at approximately 20 N. A safer operating value with margin from stall is approximately 5 N. This means that the screw drive is sufficient for a lightweight mechanism, but it must be verified in a physical prototype, especially with regard to friction, guide misalignment and operation at the end positions.

The system also uses an MG90 servo. For a conservative case with a current of 0.75 A and a movement time of 1 s, the energy used by one servo movement is:

ES = 5 V · 0, 75 A ·

1 s
3600 s/h ≈ 0, 0010 W h

Even with ten such movements, the servo uses approximately 0.01 Wh. Limiting idle current is much more important than the energy used by one movement, so the design disconnects power from the servos and motor driver in sleep mode.

For an example operating cycle consisting of 16 rotation motor corrections, several support movements and several servo movements, the energy used by the actuators under normal operating conditions is approximately:

EDRIV E ≈ 0, 036 W h

Compared with a pack containing approximately 5 Wh, this is less than 1% of its stored energy. Under good lighting conditions, the panels could replace this energy within several minutes. Even in a short-term overload case in which the rotation motor periodically operates close to the H-bridge current limit, the energy used by the actuators remains much lower than the energy that can be harvested from the panels.

These calculations indicate that actuator energy consumption should not prevent self-sufficient system operation. Correct operation still requires limiting the number of movements, keeping the microcontroller in sleep mode between measurements, disconnecting actuator power after movement, and preventing prolonged motor or servo stalls. Actual current consumption during startup, steady movement and operation at the end positions should be verified in a physical prototype, because the real mechanical resistance will determine the actuator safety margin.

The calculations are approximate and do not include a detailed breakdown of every loss in the system. The energy balance includes the main losses in the conversion path through the assumed efficiency of the converter and remaining charging path. Detailed losses in wires, PCB traces, the H-bridge, switching components and other parts are not included. Energy used by the microcontroller during short active periods is also not calculated separately because its power consumption during actuator movement is much lower than that of the motors and servo. In sleep mode, the STM32L0 itself should draw so little current that it can be treated as negligible in a preliminary energy balance compared with the energy stored in the cell pack and used by the actuators. However, the sleep current of the complete PCB should be measured in a physical prototype. The actual standby current may be dominated not by the microcontroller, but by other system components such as converters, measurement circuits, pull-up resistors or indicators.

## 5.2 Mechanical Collision Verification

During analysis of the mechanical model, the placement of electronic components was checked relative to moving and drive components. The purpose was to determine whether the PCB and through-hole components would collide with the motors, transmissions or enclosure after assembly. The analysis identified a collision between one filtering capacitor and the motor located in the base.

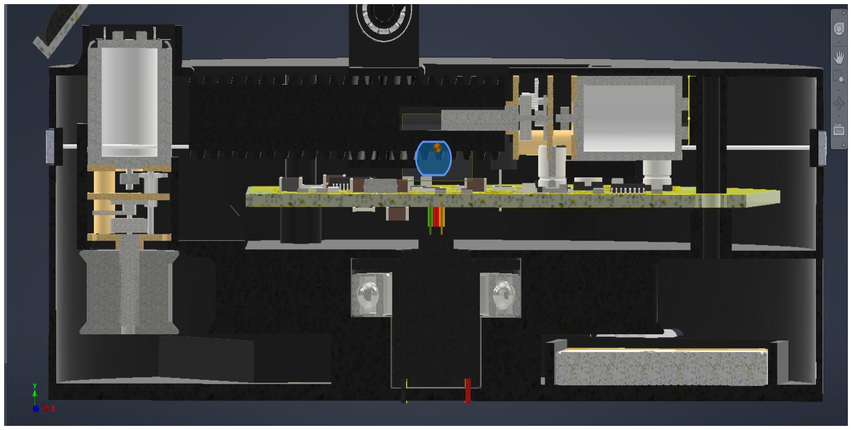
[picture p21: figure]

Figure 5.1: Close-up of the collision between the filtering capacitor and the motor.

The component involved provides filtering in the power path. Because the design also contains other decoupling and filtering capacitors, the simplest solution for this prototype version is to leave this particular capacitor unpopulated. Its footprint can remain on the PCB, but the component should not be soldered during assembly. This avoids the mechanical conflict without redesigning the complete board.

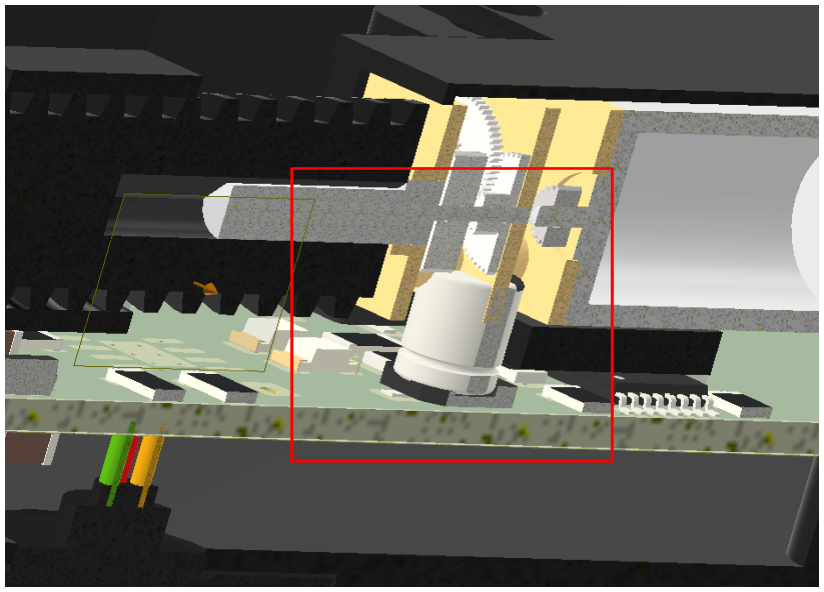
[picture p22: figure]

Figure 5.2: Device model cross-section showing the PCB, motor and mechanical components.

This component should be marked in the assembly documentation as DNP (do not populate). In a future PCB revision, the capacitor should be moved, replaced with a lower-profile component, or the motor placement should be changed. Leaving it unpopulated is acceptable in the current prototype because its function is supplementary and the remaining filtering components still provide basic power-supply stabilization and decoupling.

## 5.3 Mechanical Verification of Actuator Selection

Mechanical validation estimates whether the selected DC motors are sufficient to move the prototype mechanism. The analysis is simplified because the actual actuator load depends on the quality of the mechanical parts, friction in the guides, transmission backlash, screw resistance and the exact distribution of panel mass. The purpose of the calculations is therefore to check the order of magnitude of the available torque and force, not to determine the exact dynamic behavior of the complete system.

The design uses two geared DC motors. The first rotates the complete mechanism around the vertical axis. It has a 298:1 gearbox, a rated speed of approximately 100 RPM at 6 V, a stall torque of approximately 4.0 kgcm and a stall current of approximately 1.6 A. The second motor rotates the lead screw and moves the fan support linearly. It has a rated speed of approximately 410 RPM at 6 V, a stall torque of approximately 1.3 kgcm and a stall current of approximately 1.6 A.

The motor that rotates the complete mechanism uses an additional 6:1 reduction provided by a GT2 belt. Because it is powered from the 5 V section, its available torque can be approximately scaled from the rated value at 6 V:

M1,5V = 4, 0 kgcm ·

5
6

≈ 3, 33 kgcm

Converted to newton-metres:

M1,5V ≈ 3, 33 · 0, 0981 ≈ 0, 33 Nm

After including the additional 6:1 reduction and assuming a belt transmission efficiency of approximately 85%, the maximum short-term torque at the mechanism rotation axis can be estimated as:

M1,out = 0, 33 Nm · 6 · 0, 85 ≈ 1, 68 Nm

This value corresponds to operation close to motor stall and should not be treated as continuously available torque. For a safer estimate, approximately 25% of this value can be used as the useful operating torque:

M1,rob ≈ 0, 25 · 1, 68 Nm ≈ 0, 42 Nm

This torque should be sufficient to rotate the prototype mechanism because the actuator does not lift the complete structure but rotates it around the vertical axis. The main loads therefore result from bearing friction, transmission resistance and inertia during acceleration and stopping. The 6:1 reduction is useful because it increases the available torque and reduces movement speed, improving control of the light-tracking system.

The output speed can be estimated in a similar way. For a 100 RPM motor at 6 V, scaled to a 5 V supply and including the 6:1 reduction, the result is:

n1,out =

100 RPM ·

5
6
6

≈ 13, 9 RPM

The software also controls the motor with PWM, so the actual movement speed will be lower. This is suitable for the mechanism because a solar tracker does not require fast rotation, only periodic panel position corrections. Even if one correction takes several seconds, device functionality is not affected.

The second motor rotates the lead screw and moves the fan support. At 5 V, its stall torque can be estimated as:

M2,5V = 1, 3 kgcm ·

5
6

≈ 1, 08 kgcm

Converted to newton-metres:

M2,5V ≈ 1, 08 · 0, 0981 ≈ 0, 106 Nm

In this case, the screw converts torque into linear force. Assuming a screw lead of 10 mm/rev and an efficiency of approximately 30% for the screw and guide system, the linear force can be estimated from:

F =

2πηM
p

where η is the mechanism efficiency, M is the torque, and p is the screw lead. Substituting the values gives:

F2,max =

2π · 0, 30 · 0, 106 Nm
0, 01 m

≈ 20 N

This is a short-term force corresponding to operation close to motor stall. A safer operating value can be taken as approximately 25% of this value:

F2,rob ≈ 5 N

This means that the screw drive should be sufficient to move the lightweight fan support, provided that the mechanism does not have excessive movement resistance. In practice, this actuator is more sensitive to manufacturing quality than the main rotation drive. Guide misalignment, excessive screw friction or components binding at the end positions could significantly increase the required torque. For this reason, smooth support movement and motor current during motion should be checked carefully in a physical prototype.

Additional protection is provided by the DRV8833 H-bridge with 0.15 Ω shunt resistors R11 and R19. For this device, current limiting is activated when the voltage at the xISEN sense input reaches approximately 0.2 V. The current limit can therefore be estimated as:

ICHOP =

0, 2 V
0, 15 Ω

≈ 1, 33 A

This value is close to the expected motor stall current at 5 V. If the mechanism stalls temporarily, the H-bridge should therefore limit the current and reduce the risk of damage to the power path. This does not mean that the motors can remain stalled for a long time. Current limiting improves electronic safety, but it also limits the maximum available torque and does not eliminate heating of the motors, H-bridge and shunt resistors.

The estimates indicate that the selected motors are sufficient for the prototype mechanism. The main rotation motor has the largest margin because of the additional 6:1 reduction and should move the mechanism without difficulty if the rotation axis does not have excessive resistance. The screw motor should also be sufficient to move the fan support, although its performance depends more strongly on friction and the manufacturing accuracy of the guide components. The next stage of work should therefore verify the current consumption of both actuators during actual movement, startup and operation at the end positions. This would confirm whether the mechanisms operate below the H-bridge current limit and whether the selected motors provide a sufficient safety margin.

# 6 Final Conclusions

The project developed the concept of a prototype energy storage system powered by photovoltaic panels. It combines electronics, mechanical design and software, allowing energy to be harvested from the panels and their position to be adjusted actively relative to the light source. The main project assumption was a positive energy balance: the energy used by the control system and actuators should remain lower than the additional energy that can be harvested through improved panel positioning.

The analysis shows that the selected architecture is reasonable for a small autonomous solar system. Four photovoltaic panels connected in series provide sufficient voltage margin for the DC/DC converter, and the 1S3P Li-Ion cell pack can operate as a small energy storage device. The energy-balance calculations indicate that the system should be able to recharge the selected cell pack under favorable lighting conditions. However, it should not be treated as a full-size, high-capacity powerbank. It is a prototype small energy source intended to power low-power loads or partially recharge devices with higher current consumption.

An important part of the project is the pseudo-MPPT algorithm and panel voltage and current measurement. This solution allows the current panel power to be evaluated and the operating point to be changed without a more complex dedicated MPPT controller. The approach is simpler and fits the prototype nature of the project, but its effectiveness must be tested under real lighting conditions. A comparison of system operation with and without active solar tracking would be particularly important.

The mechanical design meets the prototype assumptions because it houses the electronics and cells, supports the actuators, and allows the panel position to be changed. The fan structure increases the active panel area while keeping the device compact. At the same time, the mechanical design requires further verification after a physical model has been built. The stiffness of printed components, transmission backlash, movement resistance, panel positioning accuracy, and ease of cell assembly and servicing should be checked in practice.

The software has a modular design and is based on a state machine. As a result, device operating modes such as startup, light tracking, pseudo-MPPT adjustment, folding and sleep are separated logically. Periodic operation and entering sleep mode after measurements or position corrections are especially important for the energy balance. This reduces average current consumption and increases the possibility of self-sufficient system operation.

The main limitation of the current project version is the lack of a built and tested physical prototype. The validation is theoretical and is based on calculations, circuit analysis, the CAD model and assumed component parameters. The next development stage should therefore be construction of the prototype, commissioning of the power path, measurement of the actual charging current, verification of sleep-mode current consumption, and evaluation of the energy used by the actuators during actual panel

positioning.

Further work should also verify the actual converter efficiency, the temperature of power-path components, system behavior under partial panel shading, and pseudo-MPPT algorithm stability. Only these tests would allow a clear assessment of whether active panel positioning provides a noticeable energy gain compared with a fixed structure. Despite these limitations, the project provides a consistent basis for building a physical prototype and further verifying the operation of a small self-sufficient solar system.

# 7 References

[1] Suzhou Hisenpower Co., Ltd. MPPT Solar Inverter: Everything You Need to Know. June 26, 2023. URL: https://www.hisenpower.com/Blogs/mppt-solarinverter-everything-you-need-to-know (https://www.hisenpower.com/Blogs/mppt-solar-inverter-everything-you-need-to-know) (visited on 06/15/2026).
[2] XL4015 180KHz 36V 5A Switching Current Buck DC/DC Converter. Rev. 1.2. XLSEMI. 2023. URL: https : / / www . xlsemi . com / datasheet / XL4015 - CN . pdf (https://www.xlsemi.com/datasheet/XL4015-CN.pdf) (visited on 04/09/2026).
[3] BQ25750: Standalone/I2C Controlled, 1- to 14-Cell Bidirectional Buck-Boost Battery Charge Controller with Direct Power Path Control. Texas Instruments. 2023. URL: https://www.ti.com/lit/ds/symlink/bq25750.pdf (visited on 04/09/2026).
[4] Christian Moyer. How To Implement External P&O Feature On BQ2575X. Tech. rep. SLUAB21. Texas Instruments, 2025. URL: https://www.ti.com/lit/pdf/sluab21 (visited on 04/09/2026).
[5] STM32L051x6 STM32L051x8 Datasheet. Datasheet – production data. STMicroelectronics. 2019. URL: https : / / www . st . com / resource / en / datasheet / stm32l051c6.pdf (https://www.st.com/resource/en/datasheet/stm32l051c6.pdf) (visited on 04/08/2026).
[6] AVR128DB28/32/48/64 Data Sheet. Datasheet. Microchip Technology Inc. 2026. URL: https://ww1.microchip.com/downloads/en/DeviceDoc/AVR128DB28- 32-48-64-DataSheet-DS40002247A.pdf (https://ww1.microchip.com/downloads/en/DeviceDoc/AVR128DB28-32-48-64-DataSheet-DS40002247A.pdf) (visited on 04/08/2026).
[7] ESP32-C6 Series Datasheet. Datasheet. Espressif Systems. 2026. URL: https: / / documentation . espressif . com / esp32 - c6 _ datasheet _ en . pdf (https://documentation.espressif.com/esp32-c6_datasheet_en.pdf) (visited on 04/08/2026).
[8] RP2040 Datasheet. Datasheet. Raspberry Pi Ltd. 2026. URL: https : / / pip (https://pip.raspberrypi.com/documents/RP-008371-DS-rp2040-datasheet.pdf) . raspberrypi . com / documents / RP - 008371 - DS - rp2040 - datasheet . pdf (https://pip.raspberrypi.com/documents/RP-008371-DS-rp2040-datasheet.pdf) (visited on 04/08/2026).
[9] Power Switching RP2040 for Low Standby Current Applications. Application note. Raspberry Pi Ltd. 2026. URL: https://pip.raspberrypi.com/categories/685-whitepapers-app-notes/documents/RP-004339-WP/Power-switching-RP2040-for-low-standby-current-applications.pdf (https://pip.raspberrypi.com/categories/685-whitepapers-app-notes/documents/RP-004339-WP/Power-switching-RP2040-for-low-standby-current-applications.pdf) (visited on 04/08/2026).

# Appendix A - PCB Layout

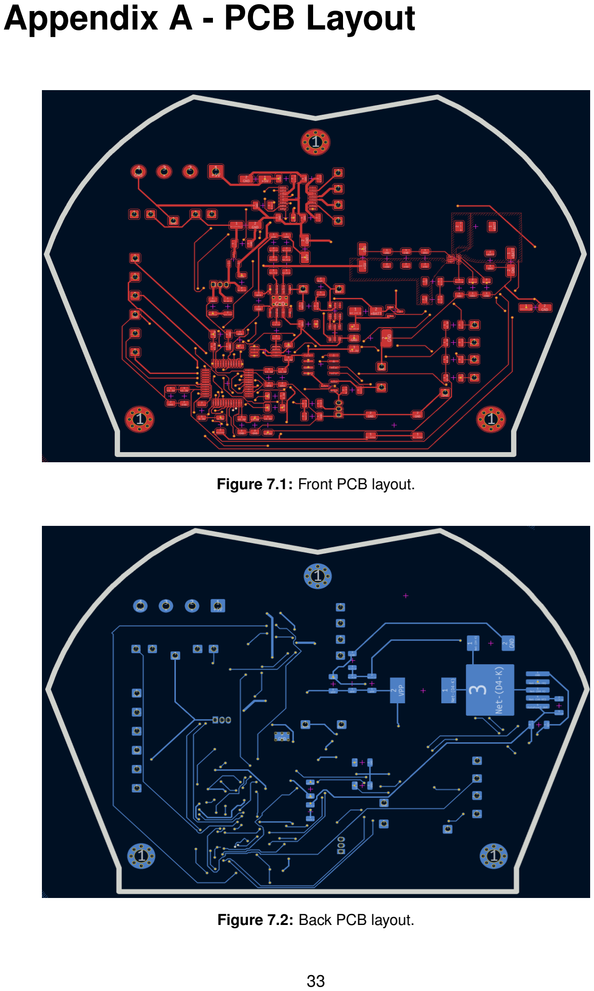
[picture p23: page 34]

Figure 7.1: Front PCB layout.

Figure 7.2: Back PCB layout.

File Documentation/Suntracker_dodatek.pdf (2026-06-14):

Suntracker – instrukcje | Załącznik do dokumentacji

## Suntracker

Instrukcja użytkownika oraz instrukcja uruchomieniowo-serwisowa

Autor: | Bartłomiej Dusza
Nr albumu: | 274546
Data: | 17 czerwca 2026 r.
Status: | krótki załącznik do dokumentacji projektowej

Dokument uzupełnia dokumentację projektu o dwie brakujące części: instrukcję użytkownika oraz instrukcję uruchomieniowo-serwisową. Nie zastępuje głównej dokumentacji, schematów, plików PCB, kodu, BOM, symulacji ani wyników testów.

### 1 Zakres i przeznaczenie

Suntracker jest prototypem autonomicznego trackera słonecznego z funkcją powerbanku solarnego i uproszczonym algorytmem MPPT. Urządzenie ustawia panel w kierunku korzystniejszego oświetlenia, mierzy parametry panelu, steruje napędami i ogranicza zużycie energii przez przechodzenie w tryb uśpienia.
Prototyp ma charakter dydaktyczny i walidacyjny. Nie jest gotowym urządzeniem do długotrwałej pracy na zewnątrz bez nadzoru oraz zabezpieczenym przed wilgocią.

### 2 Instrukcja użytkownika

### 2.1 Zasady bezpieczeństwa

- Nie uruchamiać prototypu podczas deszczu, przy wysokiej wilgotności ani na przewodzącym podłożu.
- Nie dotykać mechanizmu podczas ruchu silników i nie blokować panelu ręką.
- Nie używać układu, jeżeli ogniwo jest spuchnięte, gorące, uszkodzone mechanicznie albo ma uszkodzoną izolację.
- Nie zwierać wyjścia ogniwa, panelu, linii 5 V ani linii 3.3 V.
- Pierwsze testy funkcji powerbanku wykonywać z obciążeniem testowym, a nie z kosztownym urządzeniem.

### 2.2 Przygotowanie do pracy

1. Ustawić urządzenie na stabilnej powierzchni, tak aby panel mógł swobodnie wykonać ruch.
2. Upewnić się, że przewody nie wchodzą w zakres pracy ramienia, śruby ani serwa.
3. Skierować panel w stronę światła lub ustawić źródło światła przed urządzeniem.
4. Przed podłączeniem obciążenia USB sprawdzić multimetrem, czy napięcie wyjściowe wynosi około 5 V.

### 2.3 Uruchomienie i normalna praca

1. Nacisnąć przycisk zasilania / wybudzenia POWER_ON.
2. Po starcie układ powinien aktywować wymagane sekcje zasilania i rozpocząć sekwencję rozkładania lub ustawiania panelu.
3. W trybie Harvest_update urządzenie szuka korzystniejszego ustawienia panelu na podstawie fotorezystorów i pomiaru mocy.
4. W trybie Harvest układ utrzymuje panel w pozycji roboczej oraz wykonuje korekty MPPT.
5. Przy słabym oświetleniu układ może ograniczyć ruchy i przejść do trybu oszczędzania energii.

Prawidłowa praca oznacza krótkie, kontrolowane ruchy mechanizmu, brak resetów mikrokontrolera oraz brak wyraźnego nagrzewania przewodów, driverów i przetwornic.

### 2.4 Wyłączenie, składanie i przechowywanie

1. Nacisnąć przycisk zasilania.
2. Poczekać, aż mechanizm zakończy ruch składania.
3. Nie odłączać ogniwa w trakcie ruchu silników, chyba że wystąpi sytuacja awaryjna.

### 2.5 Sytuacje awaryjne

Test należy natychmiast przerwać, jeżeli pojawi się dym, zapach przegrzanej elektroniki, nadmierne nagrzewanie ogniwa, ciągły reset układu, blokada mechanizmu, iskrzenie albo napięcie 5 V / 3.3 V wyraźnie odbiega od wartości nominalnej.

1/2

Suntracker – instrukcje | Załącznik do dokumentacji

### 3 Instrukcja uruchomieniowo-serwisowa

### 3.1 Wymagane narzędzia

Multimetr | sprawdzenie zwarć, polaryzacji i napięć 3.3 V, 5 V, ogniwa oraz panelu.
Zasilacz laboratoryjny | pierwsze uruchomienie z ograniczeniem prądowym.
ST-Link / SWD | programowanie mikrokontrolera STM32L0.
Komputer z IDE | kompilacja i wgranie kodu.
Lampa / źródło światła | test fotorezystorów i algorytmu śledzenia.
Obciążenie testowe | sprawdzenie wyjścia 5 V oraz funkcji powerbanku.

### 3.2 Kontrola przed pierwszym zasileniem

1. Porównać obsadzenie PCB z BOM i schematem.
2. Sprawdzić polaryzację ogniwa, panelu, diod i kondensatorów elektrolitycznych.
3. Zmierzyć rezystancję między VBAT–GND, 5V–GND, 3V3–GND oraz PANEL+–PANEL-. Nie powinno być zwarcia.
4. Sprawdzić, czy mechanika porusza się swobodnie w przewidzianym zakresie.
5. Sprawdzić kolizje elementów PCB z silnikiem, śrubą, serwem i ramieniem.

### 3.3 Pierwsze uruchomienie elektroniki

1. Odłączyć silniki, serwo i obciążenie USB.
2. Podłączyć zasilanie przez zasilacz laboratoryjny z ograniczeniem prądu albo użyć sprawdzonego ogniwa 1S.
3. Sprawdzić stabilność napięcia 3.3 V. Następnie sprawdzić linię 5 V, jeżeli jest aktywna.
4. Sprawdzić, czy mikrokontroler nie resetuje się cyklicznie.
5. Zweryfikować komunikację I2C z układami INA219 i MCP40xx, przy pomocy debuggera.

### 3.4 Programowanie mikrokontrolera

1. Podłączyć GND, SWDIO, SWCLK oraz opcjonalnie NRST programatora ST-Link.
2. Wybrać wariant płytki / mikrokontrolera zgodny z użytym STM32L0.
3. Upewnić się, że środowisko zawiera wymagane biblioteki: STM32, Wire/I2C, timery, STM32LowPower, STM32RTC, INA219 i MCP40xx.
4. Skompilować i wgrać firmware. Po wgraniu wykonać reset układu i sprawdzić reakcję na przycisk POWER_ON.

### 3.5 Uruchomienie napędów i czujników

Napędy należy dołączać stopniowo. Najpierw testuje się jeden silnik DC w obu kierunkach, potem drugi silnik, następnie serwo w ograniczonym zakresie. Jeżeli kierunek ruchu jest przeciwny do oczekiwanego, należy zamienić przewody silnika albo odwrócić logikę w funkcji sterującej.
Fotorezystory należy sprawdzić w równomiernym oświetleniu i przy zasłanianiu kolejnych czujników. Oświetlenie jednej strony powinno powodować zmianę wskazywanego kierunku. Jeżeli kierunki są przesunięte, należy poprawić mapowanie pinów lub opis orientacji czujników.

### 3.6 Test MPPT i trybu uśpienia

Dla MPPT należy sprawdzić odczyt napięcia i prądu z INA219 oraz reakcję układu na zmianę oświetlenia lub obciążenia. Zmiana nastawy MCP40xx powinna wpływać na warunki pracy układu ładowania. Jeżeli algorytm oscyluje zbyt mocno, należy zmniejszyć krok zmian lub wydłużyć czas stabilizacji pomiaru.
Dla trybu uśpienia należy potwierdzić, że funkcja System_Sleep() wyłącza zbędne sekcje zasilania, ustawia wejścia mostków w stan bezpieczny i pozwala wybudzić układ przyciskiem. Po zmianach w przerwaniach warto wykonać kilka cykli: start – praca – sleep – wybudzenie.

2/2

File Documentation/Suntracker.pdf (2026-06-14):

# Projekt "Suntracker"

Dokumentacja koncowa teoretycznego projektu ´


Autor | Inz. Bartłomiej Dusza ˙
Data | 17.06.2026
Prowadz ˛acy | dr inz. Krzysztof Kwoka ˙

Niniejszy dokument stanowi podsumowanie projektu wykonanego na poczet zaj˛ec : "Systemy ´ elektroniczne w mechatronice"

# Spis tresci ´

1 Cel i zało˙zenia projektu | 2
2 Elektronika | 3
3 Mechanika | 13
4 Oprogramowanie | 19
4.3 Algorytm sledzenia poło ´ | zenia sło ˙ | nca | ´ | 20
4.6 Zarz ˛adzanie energi ˛a i tryb uspienia | ´ | 22
5 Walidacja | 23
6 Wnioski koncowe | 32 ´
7 Bibliografia | 34

# 1 Cel i zało˙zenia projektu

Celem projektu jest zaprojektowanie prototypowego systemu magazynowania energii zasilanego z paneli fotowoltaicznych. Układ ma pełnic funkcj˛e niewielkiego, autonomicz- ´
nego ´zródła energii, które moze ładowa ˙ | c ogniwo Li-Ion oraz zasila ´ | c odbiornik poprzez ´
sekcj˛e 5 V. W odróznieniu od prostych, nieruchomych układów solarnych, projektowany ˙ system został wyposazony w mechanizm ustawiania paneli wzgl˛edem kierunku padania ˙ swiatła. Rozwi ˛azanie to ma na celu zwi˛ekszenie czasu efektywnego nasłonecznienia ´
paneli oraz popraw˛e ilosci energii mo ´ | zliwej do pozyskania w ci ˛agu dnia. ˙
Istniej ˛ace rozwi ˛azania tego typu mozna podzieli ˙ | c na kilka grup. Najprostsze systemy ´
fotowoltaiczne wykorzystuj ˛a panele zamocowane na stałe pod wybranym k ˛atem. Rozwi ˛azanie takie jest tanie, proste i niezawodne, jednak nie pozwala na aktywne dopasowanie
połozenia panelu do aktualnej pozycji sło ˙ | nca. Bardziej zaawansowane konstrukcje ´
wykorzystuj ˛a jednoosiowe lub dwuosiowe trackery solarne, które zmieniaj ˛a połozenie ˙
paneli w czasie pracy. Trackery jednoosiowe najcz˛esciej ´ | sledz ˛a ruch sło ´ | nca ze wschodu ´
na zachód, natomiast trackery dwuosiowe umozliwiaj ˛a dodatkow ˛a korekt˛e k ˛ata na- ˙ chylenia panelu. Zwi˛eksza to potencjalny uzysk energii, ale jednoczesnie komplikuje ´ konstrukcj˛e mechaniczn ˛a, elektronik˛e steruj ˛ac ˛a oraz pogarsza bilans energetyczny przez koniecznos´c zasilania nap˛edów. ´

W projektowanym prototypie przyj˛eto rozwi ˛azanie posrednie, którego celem nie jest ´ maksymalizacja mocy za wszelk ˛a cen˛e, lecz sprawdzenie sensownosci małego, sa- ´ mowystarczalnego układu solarnego. Kluczowym załozeniem projektu jest dodatni ˙ bilans energetyczny, czyli sytuacja, w której energia zuzywana na sterowanie, pomiary i ˙ pozycjonowanie paneli jest mniejsza niz energia dodatkowo uzyskana dzi˛eki korzystniej- ˙
szemu ustawieniu paneli. Z tego powodu układ powinien pracowac okresowo, wi˛ekszo ´ | s´c´
czasu pozostaj ˛ac w trybie obnizonego poboru mocy, a nap˛edy powinny by ˙ | c aktywne ´
tylko podczas zmiany połozenia paneli. ˙

Załozono wykorzystanie czterech niewielkich paneli fotowoltaicznych poł ˛aczonych sze- ˙ regowo, układu pomiaru napi˛ecia i pr ˛adu paneli, przetwornicy DC/DC, układu ładowania i zabezpieczenia ogniwa oraz mikrokontrolera nadzoruj ˛acego prac˛e całosci. System po- ´ winien umozliwia ˙ c pomiar aktualnej mocy generowanej przez panele, regulacj˛e punktu ´ pracy w formie uproszczonego algorytmu pseudo-MPPT oraz sterowanie nap˛edami odpowiedzialnymi za ustawianie konstrukcji. Istotnym wymaganiem jest równiez mo ˙ zli- ˙ wos´c bezpiecznego ładowania ogniwa Li-Ion oraz odł ˛aczania elementów wykonawczych ´ w stanach, w których nie s ˛a potrzebne.

Zakres projektu obejmuje wykonanie modelu prototypu, zaprojektowanie toru zasilania i
sterowania, przygotowanie konstrukcji mechanicznej umozliwiaj ˛acej zmian˛e poło ˙ | zenia ˙
paneli oraz opracowanie podstawowego oprogramowania steruj ˛acego. Projekt ma charakter teoretyczny.

# 2 Elektronika

Schemat blokowy systemu przedstawia ogóln ˛a struktur˛e toru zasilania, pomiaru oraz sterowania urz ˛adzenia. Zródłem energii s ˛a panele fotowoltaiczne, których napi˛ecie i ´ pr ˛ad s ˛a mierzone w celu okreslenia aktualnej mocy dostarczanej przez układ. Nast˛epnie ´ energia trafia do przetwornicy DC/DC oraz sekcji BMS odpowiedzialnej za ładowanie i zabezpieczenie ogniwa, które pełni rol˛e magazynu energii. Z ogniwa zasilane s ˛a osobne sekcje napi˛eciowe: 3,3 V dla cz˛esci logicznej oraz 5 V dla elementów wykonaw- ´ czych, głównie silników. Centralnym elementem steruj ˛acym jest mikrokontroler, który na podstawie danych pomiarowych nadzoruje prac˛e układu pseudo-MPPT oraz steruje mostkiem H odpowiedzialnym za ustawianie połozenia paneli. ˙

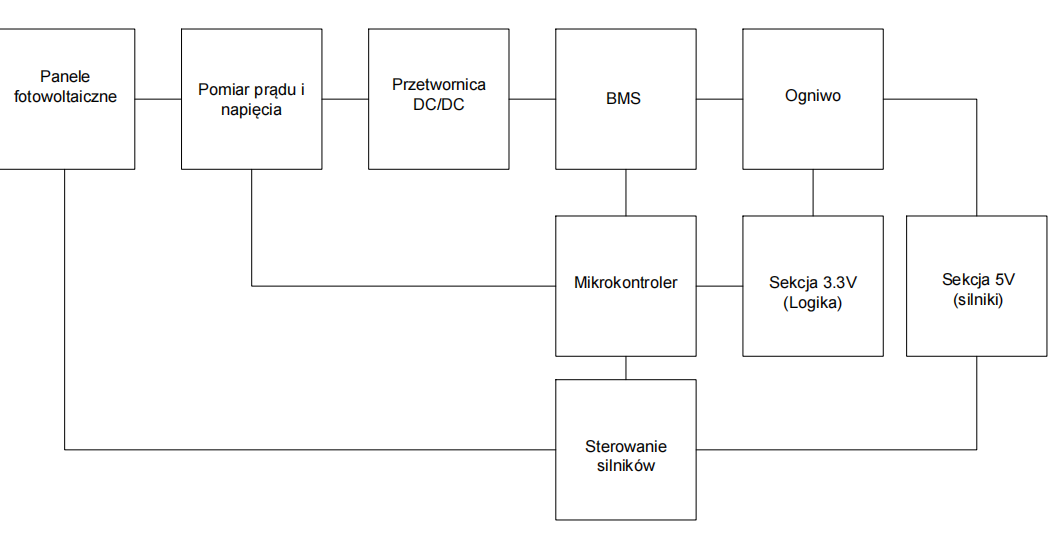
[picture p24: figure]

Rysunek 2.1: Schemat blokowy systemu.

## 2.1 Panele fotowoltaiczne

Najistotniejszym elementem systemu bez w ˛atpienia bedzie jego ´zródło zasilania. Panele fotowoltaiczne s ˛a nieliniowymi ´zródłami zasilania wykorzystuj ˛acymi zjawisko wewn˛etrznego efektu fotoelektrycznego. Przez t˛e nieliniowos´c do uzyskania maksimum mocy ´ wymagany jest układ MPPT (ang. maximum power point tracking). Ide ˛a jest to, aby
dobrze dobierac pr ˛ad pobierany przez system z panelu, aby otrzymywa ´ | c najwi˛ecej ´
mocy.


Rysunek 2.2: Wykres pr ˛adu w funkcji napi˛ecia panelu[1].

Sterowanie takim panelem opiera si˛e na odczytaniu aktualnej wartosci napi˛ecia oraz ´ pr ˛adu, a nast˛epnie odpowiednim wysterowaniu przetwornicy DC/DC, do której wejscia ´
podł ˛aczony jest panel. Panele fotowoltaiczne mozna ł ˛aczy ˙ | c szeregowo, sumuj ˛ac po- ´
szczególne napi˛ecia, równolegle, sumuj ˛ac pr ˛ady paneli, lub hybrydowo. W celu realizacji projektu zdecydowano si˛e na wykorzystanie 4 identycznych paneli o napi˛eciu nominalnym 5,5 V oraz mocy 0,4 W kazdy, poł ˛aczonych w konfiguracji szeregowej. Wybór ˙ ten podyktowany jest minimalizacj ˛a strat na liniach przesyłowych wynikaj ˛acych z faktu, ze przewody maj ˛a własn ˛a rezystancj˛e. Panele po podł ˛aczeniu szeregowym cechuj ˛a ˙ si˛e napi˛eciem nominalnym około 22 V oraz moc ˛a ł ˛aczn ˛a 1,6 W, co daje odpowiednio
duzy zapas napi˛ecia, aby przetwornica mogła pracowa ˙ | c równie ´ | z przy mniejszym na- ˙
słonecznieniu. Wad ˛a tej konfiguracji jest jej wrazliwo ˙ | s´c na ró ´ | znice w nasłonecznieniu ˙
poszczególnych paneli. W sytuacji, gdy jeden z paneli b˛edzie niepoprawnie oswietlony, ´
moze on znacz ˛aco ogranicza ˙ | c prac˛e całego ła ´ | ncucha. Alternatywnym rozwi ˛azaniem ´
mogłoby byc poł ˛aczenie dwóch paneli szeregowo w jeden pakiet, a nast˛epnie poł ˛aczenie ´ takich pakietów równolegle, otrzymuj ˛ac około 11 V na wyjsciu. Wad ˛a tego rozwi ˛aza- ´
nia jest mozliwo ˙ | s´c przepływu pr ˛adu z lepiej o ´ | swietlonego pakietu do pakietu słabiej ´
oswietlonego. Rozwi ˛azaniem tego problemu jest dodanie diod Schottky’ego, które unie- ´ mozliwiaj ˛a przepływ pr ˛adu wstecznego, jednak odbywa si˛e to kosztem spadku napi˛ecia ˙
i dodatkowych strat mocy. W przypadku poł ˛aczenia szeregowego mozna zastosowa ˙ | c´
równiez diody bocznikuj ˛ace, podł ˛aczone równolegle do poszczególnych paneli. Ich ˙ zadaniem jest umozliwienie przepływu pr ˛adu z pomini˛eciem panelu, który został zacie- ˙ niony lub chwilowo generuje znacznie mniejsz ˛a moc niz pozostałe. Dzi˛eki temu jeden ˙
słabo oswietlony panel nie blokuje pracy całego ła ´ | ncucha, cho ´ | c odbywa si˛e to kosztem ´
obnizenia całkowitego napi˛ecia zestawu. Rozwi ˛azanie to poprawia odporno ˙ | s´c układu ´
na cz˛esciowe zacienienie, ale zwi˛eksza liczb˛e elementów i wprowadza dodatkowe ´
straty na diodach. Mozliwy byłby równie ˙ | z wariant poł ˛aczenia wszystkich czterech paneli ˙
równolegle. W takim przypadku napi˛ecie wyjsciowe pozostałoby na poziomie około 5,5 ´ V, natomiast pr ˛ad nominalny zwi˛ekszyłby si˛e do około 0,29 A, przy zachowaniu ł ˛acznej
mocy około 1,6 W. Zalet ˛a takiego rozwi ˛azania byłaby wi˛eksza odpornos´c na cz˛e ´ | sciowe ´
zacienienie pojedynczego panelu, jednak tak niskie napi˛ecie znacz ˛aco ograniczałoby

mozliwo ˙ | s´c zastosowania przetwornicy obni ´ | zaj ˛acej napi˛ecie i wymagałoby raczej u ˙ | zycia ˙
przetwornicy podwyzszaj ˛acej. W praktyce wariant ten byłby mniej korzystny dla przy- ˙ j˛etej architektury zasilania, poniewaz generowałby wi˛eksze pr ˛ady w przewodach oraz ˙ wi˛eksze straty przewodzenia.

## 2.2 Przetwarzanie energii

Pod wzgl˛edem teoretycznym nalezy podzieli ˙ | c ten podrozdział na sekcje przetwornicy ´
odpowiedzialnej za implementacj˛e pseudo-MPPT oraz sekcje przetwornic przetwarzaj ˛acych napi˛ecie z baterii do napi˛ec odpowiednich na podzespoły. ´
Sekcja przetwornicy moze zosta ˙ | c zrealizowana na trzy główne sposoby. Pierwszym z ´
nich jest wykonanie własnej przetwornicy dyskretnej, zbudowanej z podstawowych elementów energoelektronicznych, takich jak cewka, dioda, tranzystor MOSFET oraz układ sterowania. Drugim podejsciem jest zastosowanie gotowego sterownika przetwornicy ´ typu DC/DC. Trzeci wariant polega na wykorzystaniu bardziej zintegrowanego układu, który oprócz samego sterowania przetwornic ˛a realizuje równiez dodatkowe funkcje, ˙ takie jak sledzenie punktu mocy maksymalnej MPPT oraz kontrola ładowania ogniwa. ´
Z punktu widzenia projektowanego systemu kluczowe były: stopien zło ´ | zono ˙ | sci wdro ´ | ze- ˙
nia, mozliwo ˙ | s´c uruchomienia układu w warunkach prototypowych, dost˛epno ´ | s´c doku- ´
mentacji oraz przydatnos´c danego rozwi ˛azania w układzie zasilanym z paneli fotowolta- ´ icznych. Porównanie rozwazanych wariantów przedstawiono w tabeli 2.1. ˙

Tabela 2.1: Porównanie wariantów realizacji sekcji przetwornicy

Rozwi ˛azanie | Zalety | Ograniczenia | Ocena
Własna przetwor-nica dyskretna | Bardzo duza elastycz- ˙ nos´c projektowa, mo ´ z-˙ liwos´c doboru elemen- ´ tów dokładnie pod wy-magania układu, poten-cjalnie wysoka spraw-nos´c.´ | Najwi˛eksza złozono ˙ s´c´ projektowa, samo-dzielne rozwi ˛azanie problemów zwi ˛aza-nych ze sterowaniem, sprz˛ezeniem zwrotnym, ˙ stabilizacj ˛a pracy oraz doborem elementów mocy. | Rozwi ˛azanie najbardziej ela-styczne, lecz zbyt złozone na etap ˙ prototypu
XL4015 [2] | Prostsza implemen-tacja, wystarczaj ˛acy zapas parametrów napi˛eciowo-pr ˛adowych oraz wbudowane pod-stawowe mechanizmy ochronne. | Mniejsza elastycznos´c´ niz w rozwi ˛azaniu dys- ˙ kretnym oraz brak na-tywnej realizacji funkcji MPPT. | Najbardziej racjo-nalny wybór dla prototypu
BQ25750 [3, 4] | Wysoki stopien integra- ´ cji, obsługa MPPT oraz funkcji zwi ˛azanych z ła-dowaniem ogniw Li-Ion. | Wi˛eksza złozono ˙ s´c´ aplikacyjna, trudniejsze wdrozenie oraz wy ˙ zsze ˙ wymagania wzgl˛edem poprawnego projektu całej sekcji zasilania. | Rozwi ˛azanie naj-bardziej zaawanso-wane funkcjonalnie

Bior ˛ac pod uwag˛e prototypowy charakter urz ˛adzenia oraz koniecznos´c ograniczenia zło- ´ zono ˙ sci układu, za najbardziej uzasadnione rozwi ˛azanie uznano zastosowanie układu ´ XL4015 [2]. W porównaniu z układem BQ25750 rozwi ˛azanie to jest prostsze do implementacji i uruchomienia, a jednoczesnie zapewnia parametry wystarczaj ˛ace dla ´
potrzeb projektowanego systemu. Nalezy jednak zaznaczy ˙ | c,´ ze układ ten nie realizuje ˙
natywnie funkcji MPPT, dlatego funkcja ta musi zostac zaimplementowana zewn˛etrznie ´
oraz nalezy osobno rozwi ˛aza ˙ | c problem profilu ładowania ogniwa. ´


Rysunek 2.3: Schemat elektryczny przetwornicy.

Druga sekcja składa si˛e z dwóch przetwornic DC/DC, z których jedna jest odpowiedzialna za zasilenie sekcji 3,3 V, a druga za 5 V. Sekcja 3,3 V pracuje przy pomocy układu MCP1825S33, którego bardzo waznym parametrem jest niski spadek (low dro- ˙ pout), który jest kluczowy ze wzgl˛edu na bezposrednie zasilanie z baterii. Ponadto ´ wykorzystano równiez układ power path, którego rol ˛a jest automatyczne przeł ˛aczenie ˙ si˛e pomi˛edzy bateri ˛a a panelami do zasilania tej sekcji.


Rysunek 2.4: Schemat elektryczny przetwornicy na 3,3 V.

Druga przetwornica oparta jest na układzie TPS61022, którego, podobnie jak wyzej, ˙
waznym parametrem jest niski spadek napi˛ecia. Widoczn ˛a na pierwszy rzut oka ró ˙ | znic ˛a ˙
jest równiez bardzo liczna reprezentacja kondensatorów. Poło ˙ | zenie wynika zarówno z ˙
dokumentacji producenta, jak i z potrzeb systemu, bowiem sekcja ta odpowiada głównie za zasilanie silników oraz przekazanie sygnału do zasilania urz ˛adzenia ładowanego
przez USB. Wyst˛epuje ich az tyle, poniewa ˙ | z silniki DC oraz serwomechanizmy podczas ˙

pracy b˛ed ˛a pobierac du ´ | zo pr ˛adu do poprawno ˙ | sci pracy oraz b˛ed ˛a wprowadza ´ | c na te ´
linie duze szumy. ˙


Rysunek 2.5: Schemat elektryczny przetwornicy na 5 V.

## 2.3 Mikrokontroler

W celu wyboru mikrokontrolera przeanalizowano cztery reprezentatywne rozwi ˛azania: STM32L0, AVR128DB, ESP32-C6 oraz RP2040. Z punktu widzenia projektowanego systemu kluczowe były: niski pobór mocy w trybach uspienia, pobór mocy w pracy ´ aktywnej, dost˛epnos´c peryferiów niezb˛ednych do pomiaru energii i sterowania nap˛e- ´ dami, mozliwo ˙ s´c pracy z napi˛eciem zasilania 3,3 V oraz wystarczaj ˛acy zapas pami˛eci ´ programu.

Tabela 2.2: Porównanie wybranych rodzin mikrokontrolerów pod k ˛atem projektowanego systemu

Rodzina | Zalety | Ograniczenia | Ocena
STM32L0 [5] | Bardzo niski pobór mocy w trybach niskomoco-wych, RTC oraz inter-fejsy I2C/SPI/USART. | Brak natywnej ł ˛acznosci ´ bezprzewodowej oraz wi˛eksza złozono ˙ s´c kon- ´ figuracji niz w prostych ˙ układach 8-bitowych. | Najlepszy wybór dla prototypu
AVR128DB [6] | Bardzo niski pobór mocy w czuwaniu, prosta archi-tektura, SleepWalking. | Nizsza wydajno ˙ s´c i ´ mniejszy zapas pami˛eci oraz funkcjonalnosci ´ niz w nowoczesnych ˙ układach 32-bitowych. | Dobry wariant dla wersji uproszczo-nej
ESP32-C6 [7] | Natywne Wi-Fi 6, Blu-etooth LE, mozliwo ˙ s´c´ zdalnej konfiguracji, bar-dzo niski pobór w Deep-sleep. | Wysokie pr ˛ady podczas pracy i transmisji, co pogarsza bilans energe-tyczny układu solarnego. | Sensowny tylko przy wymaganej ł ˛acznosci ´
RP2040 [8, 9] | Duza elastyczno ˙ s´c, dwa ´ rdzenie Cortex-M0+, 264 kB SRAM, PIO. | Koniecznos´c zewn˛etrz- ´ nej pami˛eci QSPI oraz niekorzystny pobór mocy w stanie czuwania. | Najsłabszy wybór do tego projektu

Najkorzystniejszym wyborem dla prototypu okazał si˛e mikrokontroler STM32L051C8 z rodziny STM32L0. Układ ten ł ˛aczy niski pobór mocy z wystarczaj ˛ac ˛a liczb ˛a peryferiów potrzebnych w projekcie, takich jak przetwornik ADC, interfejs I²C do komunikacji z czujnikiem INA219, timery, RTC oraz wyjscia cyfrowe do sterowania sekcjami zasilania ´ i nap˛edami. W porównaniu z rodzin ˛a STM32L4 wybrany układ ma mniejsz ˛a wydajnos´c´ oraz mniejszy zapas pami˛eci, jednak w tym projekcie wazniejszy był niski pobór mocy, ˙ prostsza struktura układu oraz wystarczaj ˛aca funkcjonalnos´c do realizacji algorytmu ´
sledzenia sło ´ | nca i pseudo-MPPT. Rodzina AVR128DB równie ´ | z charakteryzuje si˛e ni- ˙
skim poborem mocy, jednak oferuje mniejsz ˛a elastycznos´c ni ´ z 32-bitowy mikrokontroler ˙ STM32 [6]. ESP32-C6 stanowi atrakcyjne rozwi ˛azanie w przypadku koniecznosci na- ´ tywnej ł ˛acznosci bezprzewodowej, lecz wysokie pr ˛ady robocze i szczytowe modułu ´ radiowego czyni ˛a go mniej korzystnym z punktu widzenia bilansu energetycznego [7]. Z kolei RP2040 wypada najmniej korzystnie w aplikacji solarno-bateryjnej o długim czasie
czuwania, poniewaz producent wskazuje pobór rz˛edu 180 ˙ | µA nawet w trybie deep sleep
i zaleca pełne odł ˛aczanie zasilania w aplikacjach wymagaj ˛acych minimalnego pr ˛adu spoczynkowego [8, 9].

Schemat sekcji mikrokontrolera oparto na układzie STM32L051C8Tx, który stanowi główn ˛a jednostk˛e steruj ˛ac ˛a w całym systemie. W projekcie przewidziano zł ˛acza programuj ˛ace i serwisowe, umozliwiaj ˛ace dost˛ep do linii SWDIO, SWCLK, NRST oraz BOOT0, ˙
co pozwala na programowanie i debugowanie układu bez koniecznosci demonta ´ | zu˙
mikrokontrolera z płytki. Linia NRST została podci ˛agni˛eta do napi˛ecia 3,3 V rezystorem 10 kΩ, natomiast linia BOOT0 została domyslnie sprowadzona do masy rezystorem ´ 10 kΩ, dzi˛eki czemu mikrokontroler po resecie uruchamia program z pami˛eci Flash. Istotnym elementem tej sekcji jest równiez filtracja zasilania, przy liniach zasilaj ˛acych ˙ zastosowano kondensatory odsprz˛egaj ˛ace 100 nF oraz kondensatory o wi˛ekszej po-
jemnosci, których zadaniem jest ograniczenie zakłóce ´ | n i chwilowych spadków napi˛ecia ´
podczas pracy układu. Dodatkowo zasilanie cz˛esci analogowej zostało odseparowane ´ za pomoc ˛a koralika ferrytowego, co poprawia odpornos´c pomiarów ADC na zakłócenia ´ generowane przez nap˛edy i przetwornice.


Rysunek 2.6: Schemat elektryczny mikrokontrolera.

Wyprowadzenia mikrokontrolera zostały podzielone funkcjonalnie zgodnie z zadaniami realizowanymi przez system. Piny PA0-PA3 odpowiadaj ˛a za sterowanie sekcjami zasilania, mi˛edzy innymi za wł ˛aczanie sterownika silników, zasilania 5 V oraz wybór trybu pracy przetwornicy. Piny PA4-PA7 wykorzystano jako wejscia analogowe do odczytu ´ czterech fotorezystorów, na podstawie których wyznaczany jest kierunek korekty połoze- ˙ nia paneli. Wejscia PB0 i PB1 przeznaczono do pomiarów zwi ˛azanych z układem MPPT, ´ natomiast piny PB2-PB5 steruj ˛a kierunkiem pracy silników DC. Linia PB6 odpowiada za wł ˛aczanie sekcji paneli, a piny PB10 i PB11 tworz ˛a magistral˛e I²C, wykorzystywan ˛a mi˛edzy innymi do komunikacji z czujnikiem INA219. Dodatkowo piny PB14 i PB15 słuz ˛a˙ do sterowania cyfrowym potencjometrem, który bierze udział w regulacji punktu pracy układu pseudo-MPPT.

## 2.4 Moduły

### 2.4.1 Battery management system - BMS

Sekcja ładowania i zabezpieczenia akumulatora została oparta na układzie TP4056 oraz układzie zabezpieczaj ˛acym DW01A współpracuj ˛acym z podwójnym tranzystorem MOSFET. TP4056 odpowiada za ładowanie pojedynczego ogniwa Li-Ion, natomiast rezystor programuj ˛acy ustala maksymalny pr ˛ad ładowania. Diody LED sygnalizuj ˛a stan pracy ładowarki, mi˛edzy innymi proces ładowania oraz jego zakonczenie. Układ DW01A ´ wraz z tranzystorami MOSFET zabezpiecza ogniwo przed nadmiernym rozładowa-
niem, przeładowaniem oraz zbyt duzym pr ˛adem, dzi˛eki czemu akumulator mo ˙ | ze by ˙ | c´
bezpiecznie wykorzystywany jako magazyn energii w systemie.

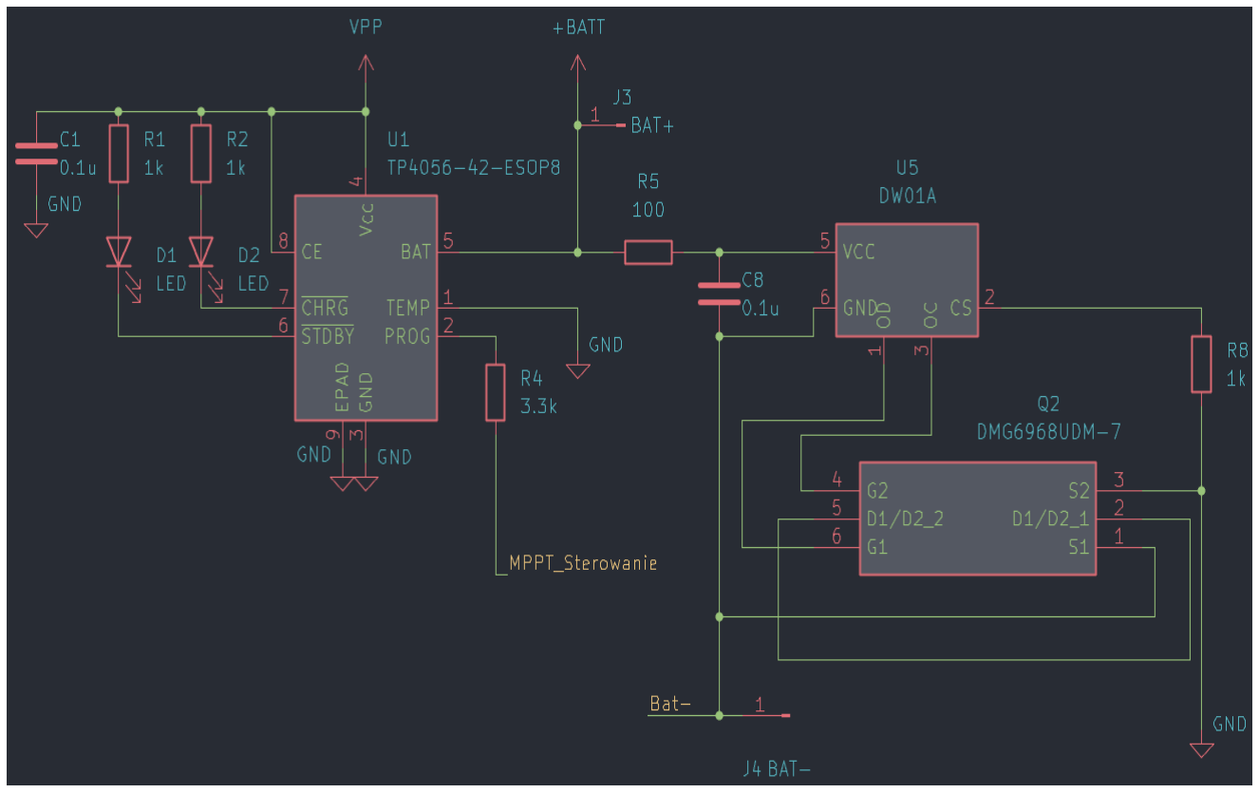
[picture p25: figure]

Rysunek 2.7: Schemat elektryczny modułu ładowania i zabezpieczenia ogniwa.

### 2.4.2 Sterowanie punktem pracy

W projekcie zastosowano potencjometr cyfrowy MCP4021-5k, który słuzy do regulacji ˙ punktu pracy układu odpowiedzialnego za pseudo-MPPT. Mikrokontroler steruje potencjometrem za pomoc ˛a linii POT_data oraz POT_cs, zmieniaj ˛ac jego rezystancj˛e w zalezno ˙ sci od aktualnie zmierzonej mocy paneli. Wyprowadzenie suwaka potencjometru ´ zostało doprowadzone do linii MPPT_Sterowanie, która wpływa na warunki pracy sekcji
przetwarzania energii. Takie rozwi ˛azanie pozwala programowo zmieniac obci ˛a ´ | zenie ˙
widziane przez panele, bez koniecznosci stosowania bardziej zło ´ | zonego sterownika ˙
MPPT.


Rysunek 2.8: Schemat elektryczny potencjometru cyfrowego.

### 2.4.3 Pomiar napi˛ecia i pr ˛adu paneli

Do pomiaru parametrów elektrycznych paneli fotowoltaicznych wykorzystano układ INA219AxD. Czujnik mierzy spadek napi˛ecia na rezystorze bocznikowym umieszczonym w torze zasilania panelu, co pozwala wyznaczyc pr ˛ad pobierany z paneli. Dodatkowo ´
układ umozliwia pomiar napi˛ecia magistrali, dzi˛eki czemu mikrokontroler mo ˙ | ze oblicza ˙ | c´
aktualn ˛a moc generowan ˛a przez panele. Komunikacja z mikrokontrolerem odbywa si˛e za pomoc ˛a magistrali I²C, a kondensator przy zasilaniu układu pełni funkcj˛e filtruj ˛ac ˛a.


Rysunek 2.9: Schemat elektryczny czujnika mocy.

### 2.4.4 Sterowanie silnikami

Sekcja sterowania silnikami DC została oparta na układzie DRV8833PW, który pełni
rol˛e podwójnego mostka H. Układ umozliwia niezale ˙ | zne sterowanie dwoma silnikami ˙
poprzez sygnały MOTOT1_IN1, MOTOT1_IN2, MOTOT2_IN1 oraz MOTOT2_IN2 generowane przez mikrokontroler. Linia DC_driver_en odpowiada za wł ˛aczanie i usypianie
sterownika, co pozwala ograniczyc pobór pr ˛adu, gdy nap˛edy nie s ˛a u ´ | zywane. W torach ˙
silników zastosowano rezystory pomiarowe o małej rezystancji, które słuz ˛a do ograni- ˙ czenia i obserwacji pr ˛adu pobieranego przez nap˛edy, a kondensatory przy zasilaniu zmniejszaj ˛a wpływ zakłócen generowanych podczas pracy silników. Ze wzgl˛edu na ´
moc wydzielan ˛a na rezystorach pomiarowych, nalezy w tym miejscu u ˙ | zy˙ c rezystorów ´
przynajmniej 0,5 W.


Rysunek 2.10: Schemat elektryczny mostka H.

Rezystory R11 oraz R19 pracuj ˛a jako boczniki pomiarowe w torze silników DC. Mimo
niewielkiej rezystancji, przy pr ˛adach rozruchowych silników moze wydziela ˙ | c si˛e na ´
nich zauwazalna moc, dlatego wymagaj ˛a one wi˛ekszej mocy znamionowej ni ˙ | z typowe ˙
rezystory sygnałowe. Zalezno ˙ | s´c´ P = I

2R powoduje, ze nawet krótkotrwały wzrost ˙ pr ˛adu znacz ˛aco zwi˛eksza obci ˛azenie cieplne tych elementów. W projekcie przewidziano ˙ równiez odł ˛aczanie zasilania serwomechanizmów za pomoc ˛a prostego przeł ˛acznika ˙ high-side, dzi˛eki czemu serwa nie pobieraj ˛a pr ˛adu w trybie uspienia lub poza momentem ´ wykonywania ruchu.

# 3 Mechanika

Cz˛es´c mechaniczna projektu została zaprojektowana jako konstrukcja prototypowa ´
umozliwiaj ˛aca ustawianie paneli fotowoltaicznych wzgl˛edem ´zródła ˙ | swiatła oraz za- ´
budow˛e głównych elementów elektronicznych. Konstrukcj˛e mozna podzieli ˙ | c na dwie ´
główne cz˛esci: podstaw˛e, w której umieszczono elektronik˛e i cz˛e ´ | s´c nap˛edow ˛a, oraz ru- ´
chomy układ paneli wykonany w formie wachlarza. Takie rozwi ˛azanie pozwala poł ˛aczyc´ funkcj˛e obudowy, mechanizmu pozycjonuj ˛acego oraz nosnika paneli fotowoltaicznych w ´ jednej zwartej konstrukcji.

Projekt mechaniczny ma charakter prototypowy, dlatego najwazniejsze było sprawdzenie ˙
poprawnosci koncepcji, rozmieszczenia elementów oraz mo ´ | zliwo ˙ | sci wykonania ruchu ´
paneli. W modelu CAD uwzgl˛edniono miejsce na płytk˛e PCB, silniki, serwomechanizm, elementy przekładni, prowadzenie przewodów oraz punkty montazowe. Dodatkowo wy- ˙ konano wizualizacje pozwalaj ˛ace ocenic rozmieszczenie podzespołów oraz potencjalne ´ kolizje elementów ruchomych.

## 3.1 Podstawa

Podstawa urz ˛adzenia została zaprojektowana w formie cylindrycznej obudowy, której zadaniem jest utrzymanie całej konstrukcji, osłoni˛ecie elektroniki oraz zapewnienie miejsca na montaz elementów nap˛edowych. Wewn ˛atrz podstawy umieszczono płytk˛e ˙ PCB, elementy zasilania, przewody oraz cz˛es´c mechanizmu odpowiedzialnego za ´ obrót układu paneli. Okr ˛agły kształt podstawy dobrze pasuje do charakteru urz ˛adzenia,
poniewaz konstrukcja mo ˙ | ze obraca ˙ | c si˛e wzgl˛edem otoczenia i nie posiada jednego ´
wymuszonego kierunku ustawienia.

W górnej cz˛esci podstawy przewidziano miejsce na płytk˛e drukowan ˛a z układem stero- ´ wania i zasilania. Płytka została umieszczona na dystansach montazowych, co pozwala ˙
odsun ˛ac j ˛a od powierzchni obudowy oraz ograniczy ´ | c ryzyko zwarcia. Rozmieszczenie ´
PCB dobrano tak, aby pozostawic miejsce na prowadzenie przewodów do paneli foto- ´ woltaicznych, silników, serwomechanizmów oraz elementów zewn˛etrznych, takich jak przycisk zasilania.


Rysunek 3.1: Widok wn˛etrza podstawy z rozmieszczeniem płytki PCB.

W obudowie przewidziano równiez otwory technologiczne i monta ˙ | zowe. Umo ˙ | zliwiaj ˛a ˙
one wyprowadzenie elementów obsługowych na zewn ˛atrz, montaz podzespołów oraz ˙
skr˛ecenie poszczególnych cz˛esci podstawy. Istotne było tak ´ | ze zachowanie przestrzeni ˙
pomi˛edzy elektronik ˛a a elementami mechanicznymi, aby ruch przekładni i osi nie kolidował z płytk ˛a PCB ani przewodami. Doceowe fizyczne złozenie zakłada wykorzystanie ˙ odpowiednich wkładek gwintowanych wtapianych.


Rysunek 3.2: Widok dolnej strony podstawy oraz przestrzeni przeznaczonej na elementy mechaniczne.

W podstawie znajduje si˛e mechanizm odpowiedzialny za przeniesienie ruchu na główn ˛a
os konstrukcji. Zastosowanie przekładni pozwala zmniejszy ´ | c wymagany moment silnika ´
oraz uzyskac wolniejszy i bardziej kontrolowany ruch. Jest to korzystne, poniewa ´ | z układ ˙
sledzenia sło ´ | nca nie wymaga du ´ | zej pr˛edko ˙ | sci obrotu, lecz stabilnego i powtarzalnego ´
ustawiania paneli wzgl˛edem ´zródła swiatła. ´


Rysunek 3.3: Widok górnej cz˛esci podstawy z elementami mechanizmu nap˛edowego. ´

Cz˛es´c nap˛edowa została umieszczona pod górn ˛a płyt ˛a podstawy. Takie rozwi ˛azanie ´ pozwala oddzielic elektronik˛e od ruchomych elementów mechanicznych oraz lepiej ´
wykorzystac dost˛epn ˛a przestrze ´ | n wewn ˛atrz obudowy. W modelu przewidziano miejsce ´
na silnik, przekładni˛e pasow ˛a wykorzystuj ˛aca standard paska GT2 oraz elementy prowadz ˛ace, które odpowiadaj ˛a za przeniesienie ruchu na główn ˛a os obrotu. ´


Rysunek 3.4: Widok mechanizmu nap˛edowego od strony dolnej podstawy.

Dolny element podstawy pełni funkcj˛e zamkni˛ecia obudowy oraz miejsca przewidzia-
nego na montaz ogniw zasilaj ˛acych. W tej cz˛e ˙ | sci konstrukcji uwzgl˛edniono przestrze ´ | n´
na ogniwa, które powinny zostac osadzone przed ostatecznym zło ´ | zeniem mechanizmu. ˙
Kolejnos´c monta ´ | zu ma tutaj znaczenie, poniewa ˙ | z po zamocowaniu koła z˛ebatego do ˙
głównej osi dost˛ep do wn˛etrza podstawy byłby znacznie utrudniony.


Rysunek 3.5: Widok dolnego elementu podstawy z miejscem na ogniwa oraz kołem z˛ebatym osi głównej.

Koło z˛ebate znajduj ˛ace si˛e przy osi głównej odpowiada za przeniesienie momentu z
mechanizmu nap˛edowego na obrót górnej cz˛esci konstrukcji. W zało ´ | zonej kolejno ˙ | sci ´
montazu najpierw umieszczane s ˛a ogniwa oraz przewody zasilaj ˛ace, a dopiero pó´zniej ˙ koło z˛ebate jest osadzane na osi głównej. W finalnym wykonaniu element ten moze˙ zostac zamocowany ciasno na osi lub dodatkowo zabezpieczony klejem, co ogranicza ´ ryzyko poslizgu podczas pracy mechanizmu. ´

Przyj˛eta konstrukcja podstawy pozwala poł ˛aczyc funkcj˛e obudowy elektroniki, miejsca ´
montazu ogniw oraz elementu no ˙ | snego dla mechanizmu obrotu. Najwa ´ | zniejszym ogra- ˙
niczeniem tej wersji jest utrudniony dost˛ep serwisowy po pełnym złozeniu urz ˛adzenia, ˙
dlatego kolejnos´c monta ´ | zu elementów ma du ˙ | ze znaczenie. W kolejnej wersji projektu ˙
mozna byłoby rozwa ˙ | zy˙ c łatwiej demontowalne mocowanie koła z˛ebatego lub osobn ˛a ´
pokryw˛e serwisow ˛a umozliwiaj ˛ac ˛a dost˛ep do ogniw bez rozbierania mechanizmu. ˙

## 3.2 Wachlarz

Cz˛es´c ruchoma urz ˛adzenia została zaprojektowana w formie wachlarza zło ´ | zonego ˙
z czterech paneli fotowoltaicznych. Panele rozmieszczono wokół centralnego punktu mocowania, co pozwala zwi˛ekszyc powierzchni˛e aktywn ˛a układu przy zachowaniu ´ zwartej konstrukcji. W porównaniu z jednym duzym panelem takie rozwi ˛azanie jest ˙

wygodniejsze w prototypie, poniewaz ułatwia rozmieszczenie paneli oraz dopasowanie ˙ ich do mechanizmu składanego.


Rysunek 3.6: Widok cz˛esci ruchomej z czterema panelami fotowoltaicznymi. ´

Panele zostały zamocowane do centralnego mechanizmu, który umozliwia zmian˛e ˙ ich połozenia wzgl˛edem podstawy. Zadaniem tego mechanizmu jest ustawienie pa- ˙ neli pod korzystniejszym k ˛atem wzgl˛edem ´zródła swiatła. W projekcie zastosowano ´ nap˛ed serwomechanizmem oraz przekładni˛e zwi˛ekszaj ˛ac ˛a uzyteczny zakres ruchu. ˙
Dzi˛eki temu mozliwe jest sterowanie poło ˙ | zeniem paneli przy u ˙ | zyciu prostego elementu ˙
wykonawczego.
Centralne mocowanie paneli pozwala zachowac wzgl˛edn ˛a symetri˛e obci ˛a ´ | zenia. Jest to ˙
istotne, poniewaz nierównomierne rozmieszczenie masy mogłoby zwi˛eksza ˙ | c wymagany ´
moment nap˛edu oraz powodowac wi˛eksze obci ˛a ´ | zenie przekładni. W modelu uwzgl˛ed- ˙
niono równiez miejsce na prowadzenie przewodów od paneli do elektroniki znajduj ˛acej ˙ si˛e w podstawie.


Rysunek 3.7: Zblizenie mechanizmu odpowiedzialnego za zmian˛e poło ˙ | zenia paneli. ˙

Podczas projektowania sprawdzono takze potencjalne kolizje pomi˛edzy elementami ˙ ruchomymi. Szczególn ˛a uwag˛e zwrócono na obszar centralnego przegubu, przekładni
oraz miejsca przejscia paneli wzgl˛edem kraw˛edzi podstawy. Taka weryfikacja jest wa ´ | zna, ˙
poniewaz w mechanizmie składanym nawet niewielkie przesuni˛ecie elementów mo ˙ | ze˙
ograniczyc zakres ruchu albo doprowadzi ´ | c do zablokowania konstrukcji. Idea ruchu ´
poszczególnych płatków wachlarza opiera si˛e na okr ˛agłym trzpieniu dolnego płata, poprzez poł ˛aczenie kształtowe, porusza sie w kanale górnego płatka.


Rysunek 3.8: Analiza przestrzeni roboczej i potencjalnych kolizji elementów ruchomych.

# 4 Oprogramowanie

## 4.1 Struktura programu

Oprogramowanie zostało podzielone na moduły odpowiadaj ˛ace głównym blokom sprz˛etowym systemu. Plik główny odpowiada za inicjalizacj˛e układu oraz obsług˛e maszyny stanów, natomiast pozostałe moduły realizuj ˛a funkcje zwi ˛azane z pomiarem mocy, sterowaniem nap˛edami, obsług ˛a fotorezystorów, cyfrowego potencjometru oraz trybów niskiego poboru mocy. Taki podział ułatwia rozwój programu oraz pozwala oddzielic´ logik˛e sterowania systemem od funkcji bezposrednio obsługuj ˛acych elementy elek- ´ troniczne. Program został przygotowany w rozszerzeniu PlatformIO aplikacji Visual studio code. Ze wzgl˛edu na prototypowy charakter projektu zdecydowano si˛e skorzystac z frameworku Arduino, w finalnej wersji urz ˛adzenia optymalniejsze i lepsze byłoby ´ przepisanie kodu na framework bardziej zblizony do architektury STM32. ˙

Program działa cyklicznie, jednak jego praca nie polega na ci ˛agłym wykonywaniu wszystkich pomiarów i ruchów. Ze wzgl˛edu na charakter zasilania solarnego najwazniejsze ˙ było ograniczenie czasu aktywnej pracy mikrokontrolera i nap˛edów. Z tego powodu zastosowano maszyn˛e stanów, która pozwala uruchamiac poszczególne funkcje tylko ´ wtedy, gdy s ˛a potrzebne.

Tabela 4.1: Podział programu na moduły

Moduł | Funkcja
main.cpp | Główna p˛etla programu i obsługa maszyny stanów.
General.cpp | Funkcje startu, uspienia, składania oraz wł ˛aczania sekcji ´ zasilania.
MPPT.cpp | Obsługa pomiaru mocy i regulacji punktu pracy paneli.
Photorezistors.cpp | Odczyt fotorezystorów i wyznaczanie kierunku korekty poło-zenia paneli. ˙
Motors.cpp | Sterowanie silnikami DC oraz serwomechanizmami.
Interrupt.cpp | Obsługa przerwan, przycisku zasilania i okresowego wybu- ´ dzania systemu.

## 4.2 Maszyna stanów systemu

Główna logika programu została oparta na maszynie stanów. Rozwi ˛azanie to pozwala
jednoznacznie okresli ´ c, w jakim trybie znajduje si˛e urz ˛adzenie oraz jakie czynno ´ | sci ´
powinny zostac wykonane w danym momencie. W programie wyró ´ | zniono pi˛e ˙ | c podsta- ´
wowych stanów: START, Harvest_update, Harvest, FOLD oraz Sleep.

Stan START odpowiada za uruchomienie systemu po wł ˛aczeniu zasilania lub wybudzeniu. W tym stanie aktywowane s ˛a wymagane sekcje zasilania, ustawiane jest pocz ˛atkowe połozenie mechanizmu, wykonywane jest wst˛epne ustawienie paneli oraz ˙ inicjalizowany jest algorytm pseudo-MPPT. Po zakonczeniu tych operacji system prze- ´ chodzi do stanu Harvest.

Stan Harvest jest podstawowym stanem pracy układu. W tym trybie wykonywana jest okresowa regulacja punktu pracy paneli fotowoltaicznych na podstawie pomiaru napi˛ecia
i pr ˛adu. Po wykonaniu aktualizacji system przechodzi do trybu uspienia, aby ograniczy ´ | c´
pobór energii.

Stan Harvest_update słuzy do ponownego ustawienia paneli wzgl˛edem aktualnego ˙
kierunku padania swiatła. Jest on wykonywany okresowo, po okre ´ | slonej liczbie cykli ´
uspienia. W tym stanie system ponownie odczytuje fotorezystory, wykonuje korekt˛e ´ połozenia paneli oraz aktualizuje punkt pracy układu. ˙

Stan FOLD odpowiada za złozenie mechanizmu. Jest wywoływany po wył ˛aczeniu ˙
systemu przyciskiem. Po złozeniu paneli urz ˛adzenie przechodzi do trybu u ˙ | spienia. ´

Stan Sleep jest stanem niskiego poboru mocy. W tym trybie odł ˛aczane s ˛a zb˛edne sekcje zasilania, w tym nap˛edy i serwomechanizmy, a mikrokontroler przechodzi w tryb
deep sleep. Wybudzenie nast˛epuje po upływie okreslonego czasu lub po naci ´ | sni˛eciu ´
przycisku.

Tabela 4.2: Stany pracy programu

Stan | Opis działania
START | Uruchomienie systemu, aktywacja zasilania, ustawienie paneli i inicjalizacja MPPT.
Harvest | Pomiar mocy paneli i aktualizacja punktu pracy pseudo-MPPT.
Harvest_update | Okresowa korekta połozenia paneli wzgl˛edem kierunku najwi˛ek- ˙ szego oswietlenia. ´
FOLD | Złozenie mechanizmu po wył ˛aczeniu systemu. ˙
Sleep | Tryb niskiego poboru mocy, odł ˛aczenie nap˛edów i uspienie ´ mikrokontrolera.
4.3 Algorytm sledzenia poło˙zenia sło ´ | nca ´
Do okreslenia kierunku najwi˛ekszego o ´ | swietlenia wykorzystano cztery fotorezystory ´
rozmieszczone w taki sposób, aby mozliwe było porównanie poziomu o ˙ | swietlenia z ´
róznych stron panelu. Program wykonuje kilka pomiarów dla ka ˙ | zdego fotorezystora, ˙
a nast˛epnie oblicza wartos´c´ sredni ˛a, co ogranicza wpływ zakłóce ´ | n i pojedynczych ´
bł˛ednych odczytów.

Na podstawie róznic pomi˛edzy odczytami wyznaczany jest kierunek, w którym powinien ˙
zostac obrócony panel. Je ´ | zeli poziom ˙ | swiatła jest zbyt niski albo ró ´ | znice pomi˛edzy po- ˙
miarami mieszcz ˛a si˛e w zadanej martwej strefie, korekta połozenia nie jest wykonywana. ˙ Pozwala to unikn ˛ac niepotrzebnej pracy silników w sytuacji, gdy zmiana ustawienia nie ´ przyniosłaby zauwazalnej poprawy. ˙

Po wykonaniu wst˛epnej korekty połozenia realizowane jest dodatkowe dostrajanie. Sys- ˙ tem wykonuje małe kroki w jedn ˛a ze stron i porównuje napi˛ecie paneli przed oraz po ruchu. Jezeli napi˛ecie wzrasta, ruch jest kontynuowany. W przypadku pogorszenia wy- ˙ niku mechanizm cofa ostatni krok. Dzi˛eki temu mozliwe jest znalezienie korzystniejszego ˙
ustawienia panelu bez koniecznosci stosowania zło ´ | zonych oblicze ˙ | n astronomicznych. ´
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

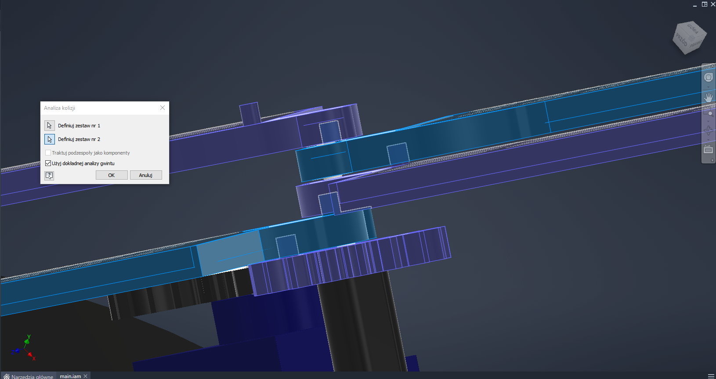
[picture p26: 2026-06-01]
Simulations/Inventor/kolizja_3-2.png

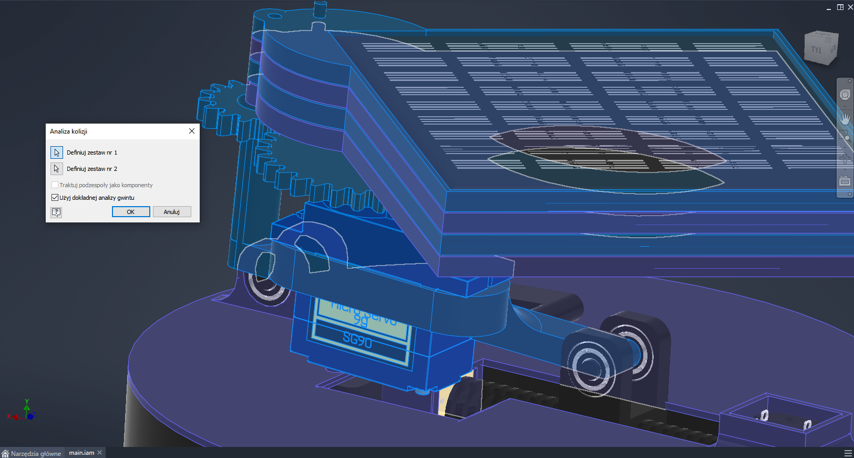
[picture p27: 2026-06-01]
Simulations/Inventor/kolizja_1.png

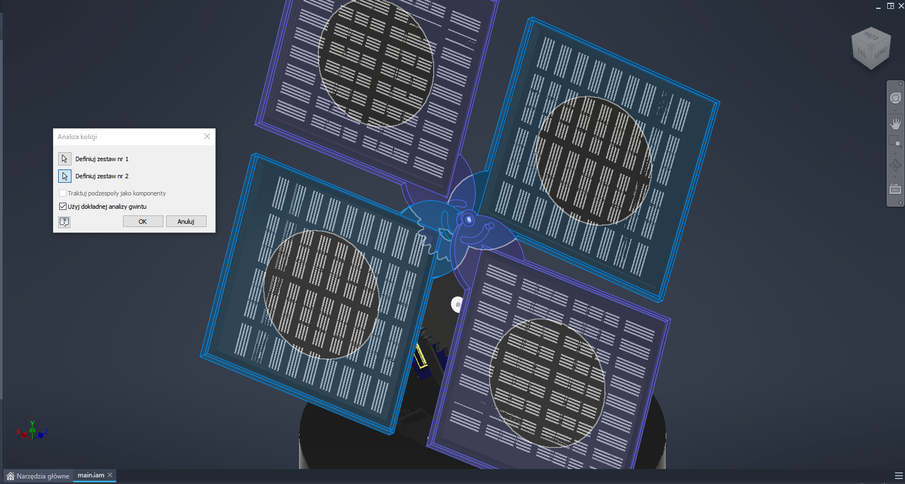
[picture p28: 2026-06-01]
Simulations/Inventor/kolizja_3-1.png

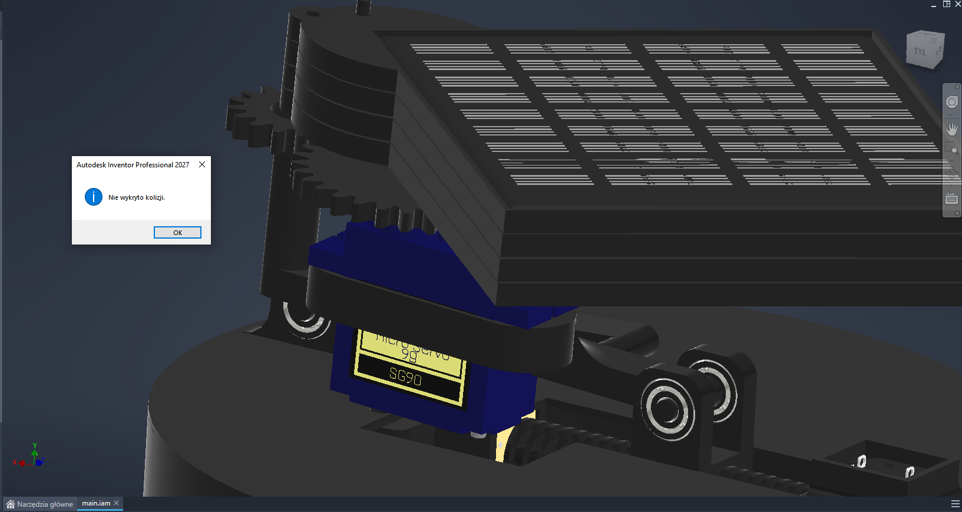
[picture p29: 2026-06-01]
Simulations/Inventor/kolizja_2.png

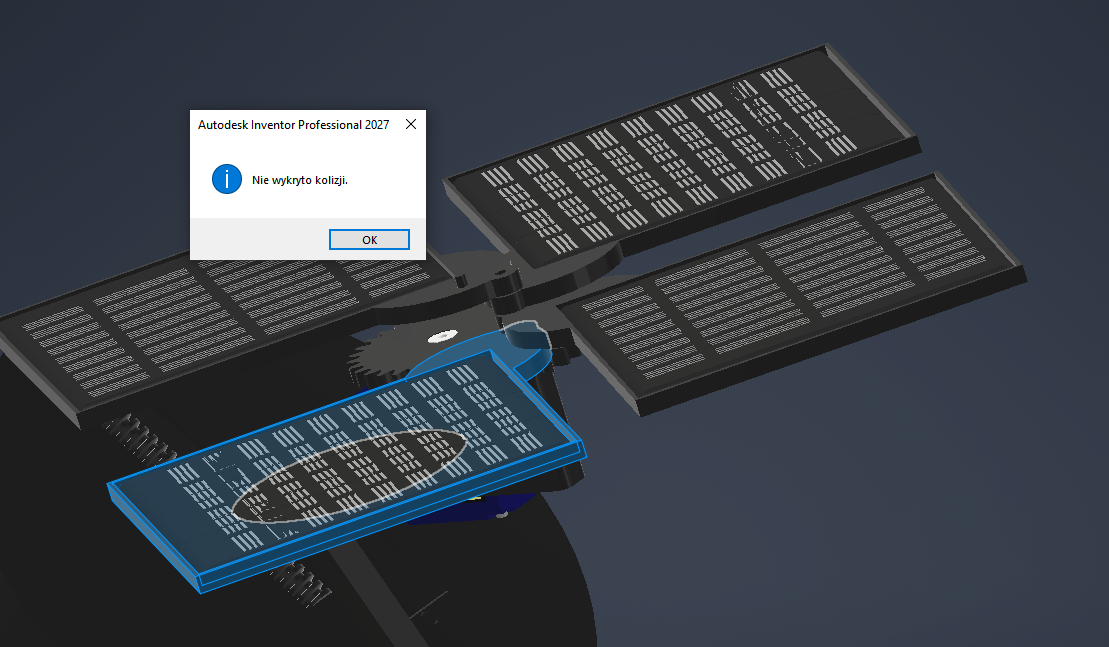
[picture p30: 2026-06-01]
Simulations/Inventor/kolizja_4.png

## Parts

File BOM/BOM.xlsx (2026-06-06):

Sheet: Elektronic
Reference | Value | Qty
C1,C8 | 0.1u | 2
C2 | 220u | 1
C3 | 4.7u | 1
C4,C6,C7,C9,C31,C32 | 1u | 6
C5,C10,C23,C25,C26,C27,C30 | 100n | 7
C11 | 330u | 1
C12 | 100u | 1
C13,C22 | 10u | 2
C14 | 33n | 1
C15 | 0.01u | 1
C16 | 100p | 1
C17,C18,C19 | 22u | 3
C20 | 2.2u | 1
C21,C29 | 470u | 2
C24 | 10u | 1
C28 | 10n | 1
D1,D2 | LED | 2
D3 | SS23 | 1
D4 | SS54 | 1
FB1 | FerriteBead | 1
J6 | 10k | 1
J7 | 10k | 1
J8 | 10k | 1
J9 | 10k | 1
L1 | 47uH/5A | 1
L2 | 1uH | 1
Q1,Q4,Q6 | IRLML6401 | 3
Q2 | DMG6968UDM-7 | 1
Q3,Q5 | 2N3904 | 2
R1,R2,R8 | 1k | 3
R3 | 0.05 | 1
R4 | 3.3k | 1
R5 | 100 | 1
R6,R14,R15,R16,R17,R18,R22,R23,R25,R26,R28,R30 | 10k | 12
R7 | 3.6k | 1
R9,R10,R13,R24,R27 | 100k | 5
R11,R19 | 0.15 | 2
R12 | 732k | 1
R20,R21,R29 | 4.7k | 3
SW1 | SW_Push | 1
U1 | TP4056-42-ESOP8 | 1
U2 | MCP1825S33 | 1
U3 | INA219AxD | 1
U4 | XL4015 | 1
U5 | DW01A | 1
U6 | MCP4021-5k | 1
U7 | TPS61022 | 1
U8 | DRV8833PW | 1
U9 | STM32L051C8Tx | 1

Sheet: Mechanic
Name | Qty
Screw M2x4 | 3
Screw M2x10 | 7
Heat-Set Threaded Inserts for Plastic M2 | 5
Nut M2 × 0.5 mm | 5
Servo MG90 | 1
Motor1 - HPCB 298:1 - Pololu 3069 | 1
Motor2 - HP 75:1 - Pololu 2361 | 1
Fotowoltaic panel 5,5V/0,4W - 65x65 mm | 4
Li-Pol Akyga 470mAh 1S 3,7V -30x30x6 mm | 3
Photoresistors 10K | 4
PETG filament | -
GT2 belt 220 mm | 1

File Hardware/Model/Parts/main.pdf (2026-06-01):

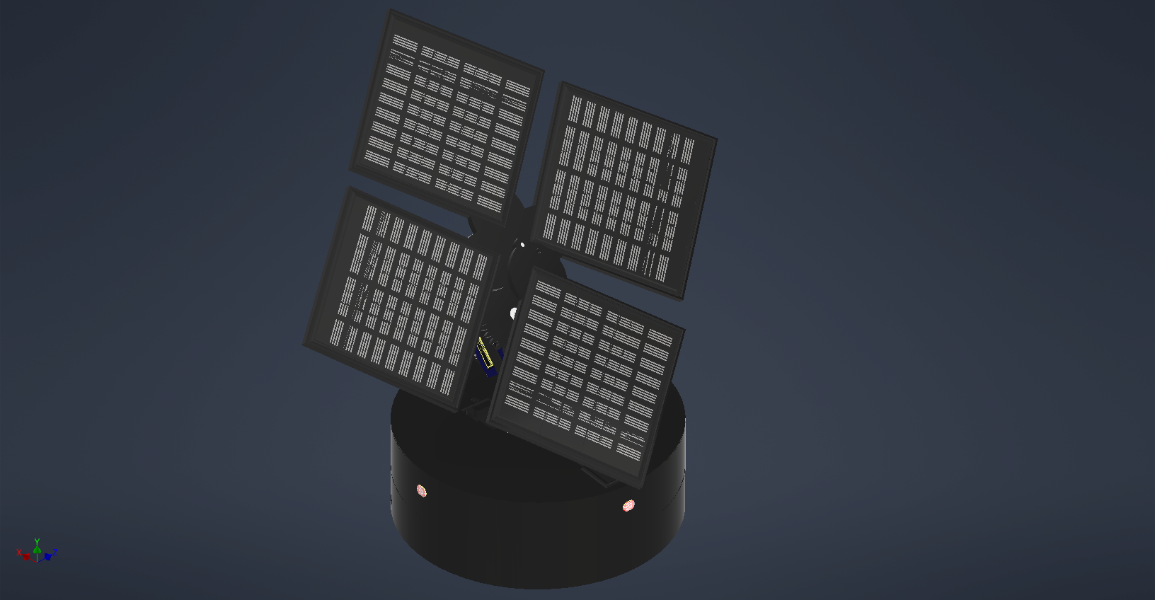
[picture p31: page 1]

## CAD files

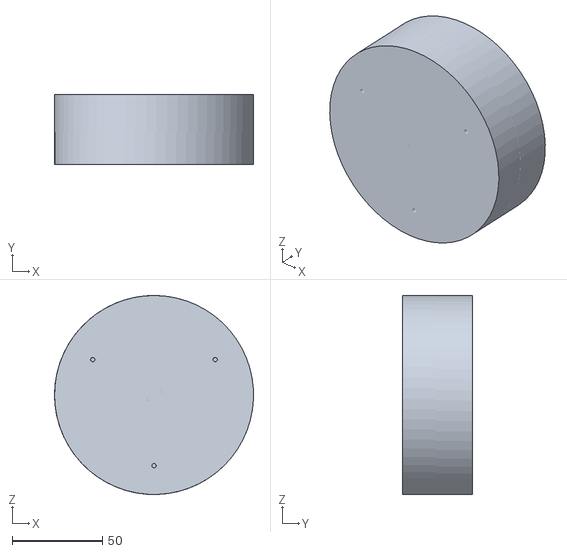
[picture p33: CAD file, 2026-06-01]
Hardware/Model/Parts/main.stl
110.5 x 39.0 x 110.5

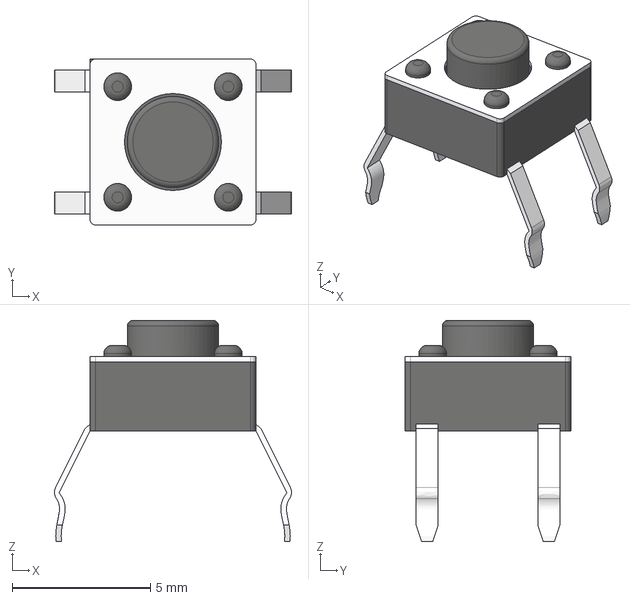
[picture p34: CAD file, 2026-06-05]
Hardware/Model/Parts/button 6x6.step
8.57 x 6.00 x 8.00 mm

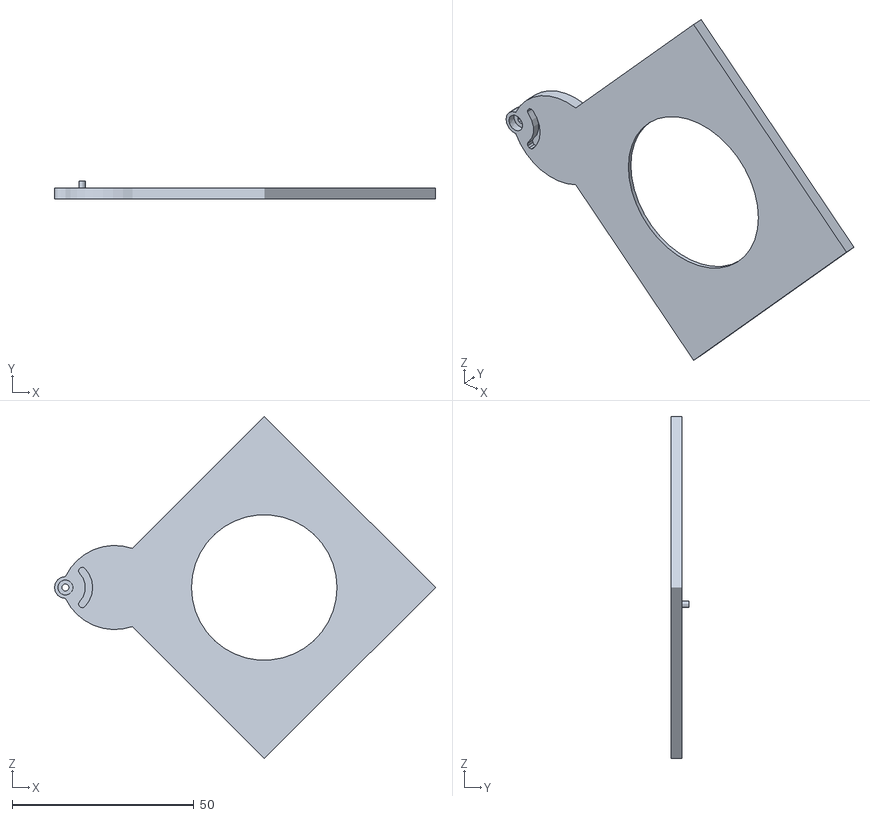
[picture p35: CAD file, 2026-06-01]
Hardware/Model/STL/flowerstand.stl
104.7 x 5.00 x 94.0

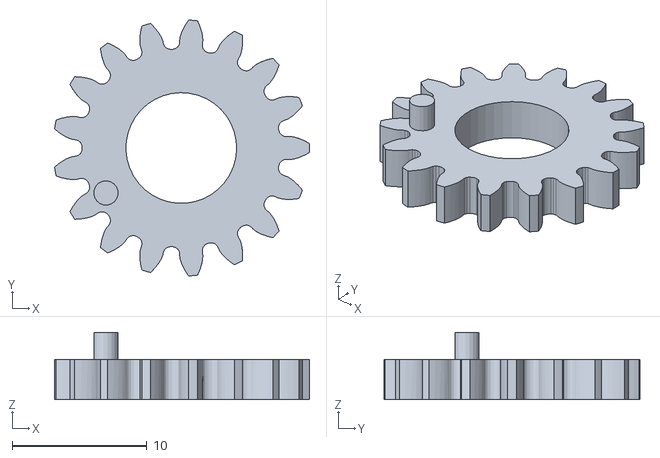
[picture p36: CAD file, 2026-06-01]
Hardware/Model/STL/Spur Gear 17 teeth.stl
18.9 x 19.0 x 5.00

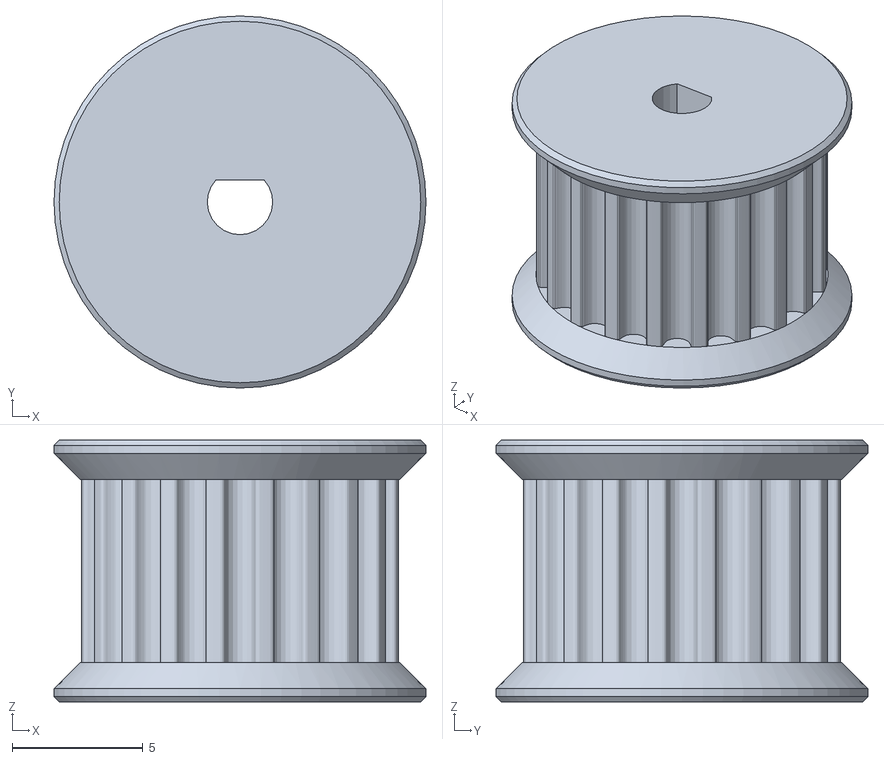
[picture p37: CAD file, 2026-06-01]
Hardware/Model/STL/pulley_drive.stl
14.2 x 14.2 x 10.0

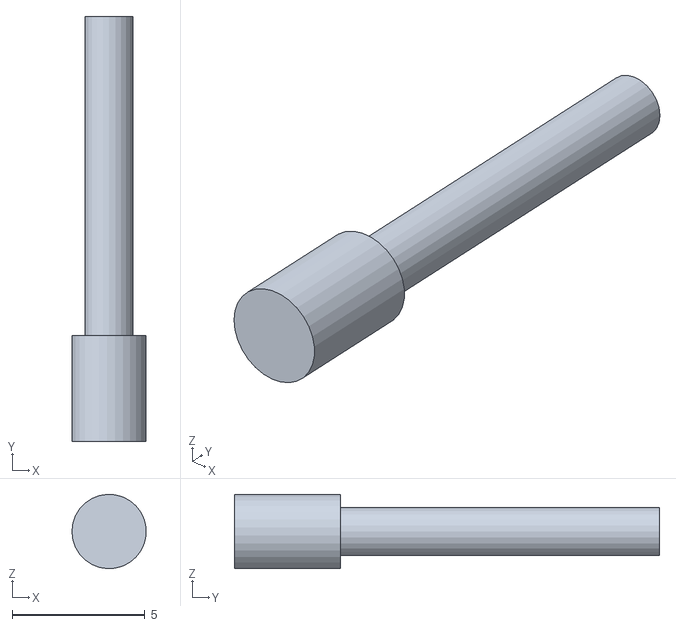
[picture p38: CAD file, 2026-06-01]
Hardware/Model/STL/Os_flower.stl
2.79 x 16.0 x 2.80

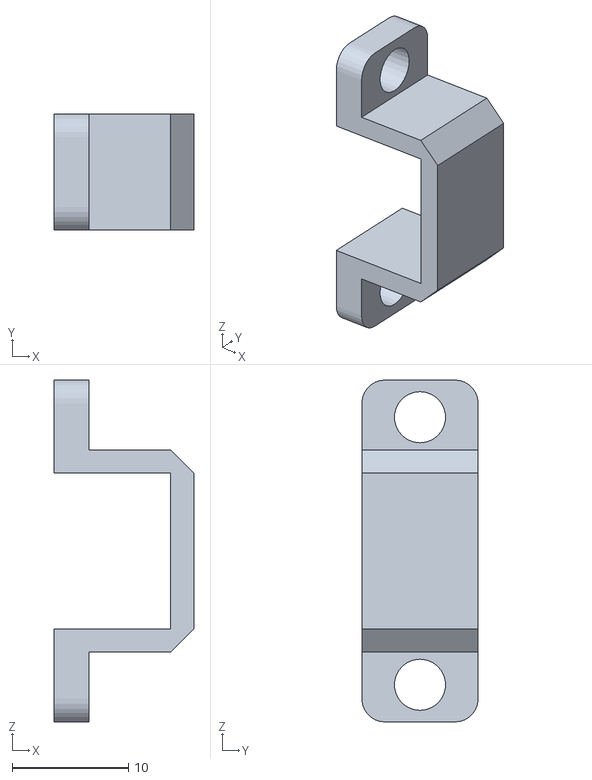
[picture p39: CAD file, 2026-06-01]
Hardware/Model/STL/silnik_lock.stl
12.0 x 10.0 x 29.4

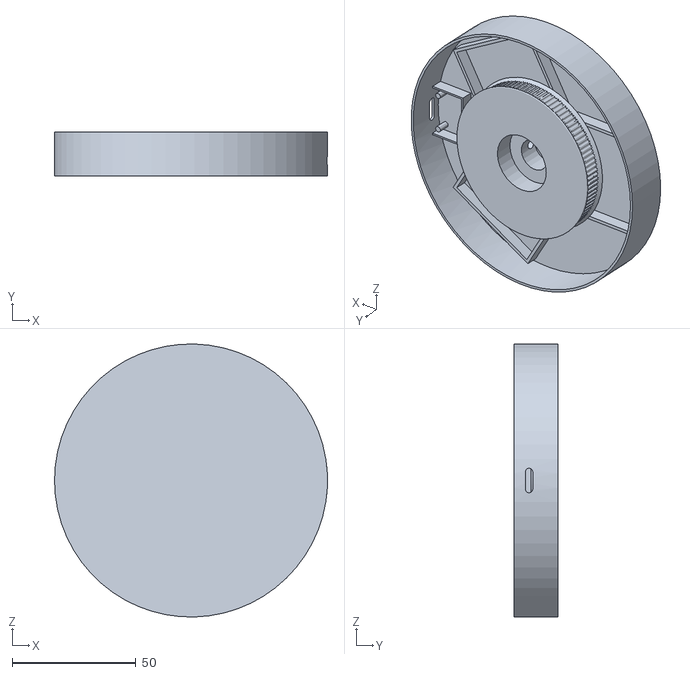
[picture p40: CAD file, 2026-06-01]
Hardware/Model/STL/Bottom_part.stl
110.5 x 18.0 x 110.5

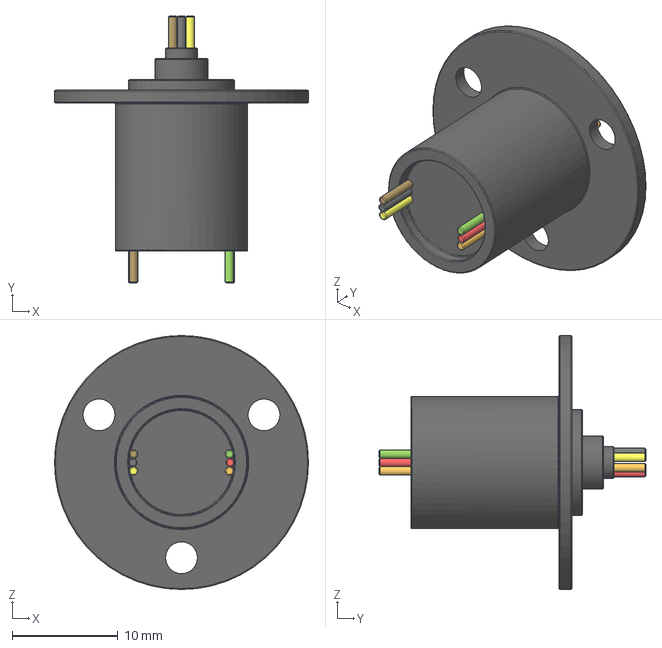
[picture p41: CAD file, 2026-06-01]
Hardware/Model/Parts/Slip Ring SRM-12-06A.step
24.0 x 25.2 x 24.0 mm

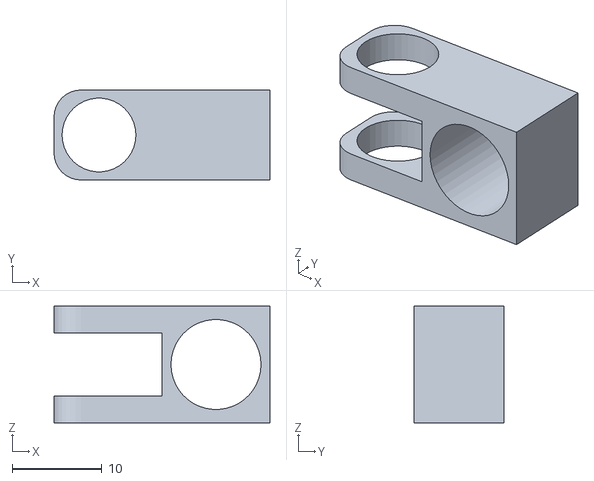
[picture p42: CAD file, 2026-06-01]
Hardware/Model/STL/konik.stl
24.0 x 10.0 x 13.0

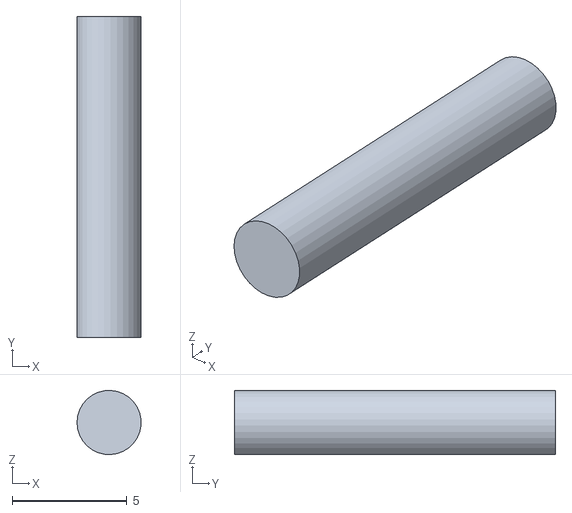
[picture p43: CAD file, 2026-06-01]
Hardware/Model/STL/OS_NORMAL.stl
2.79 x 14.0 x 2.80

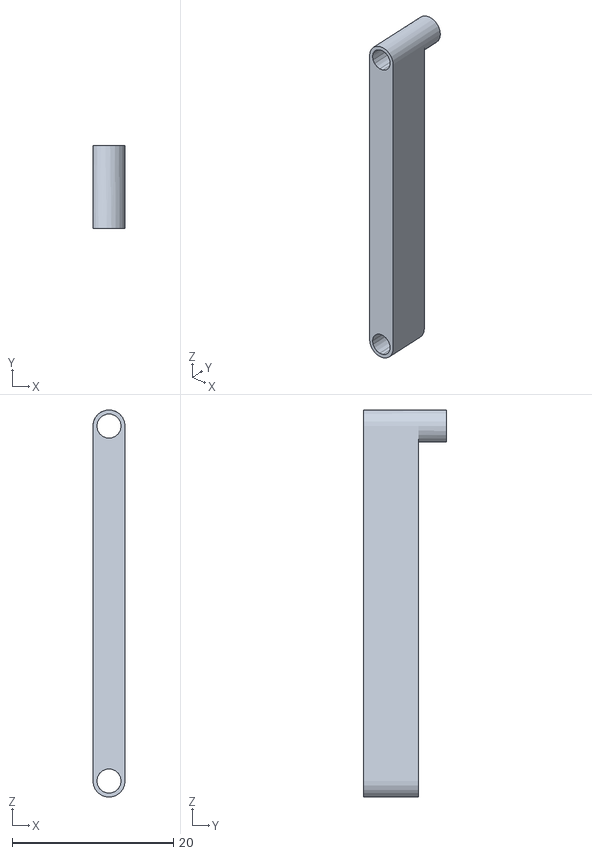
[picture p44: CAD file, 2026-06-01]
Hardware/Model/STL/link_sub.stl
4.00 x 10.3 x 48.0

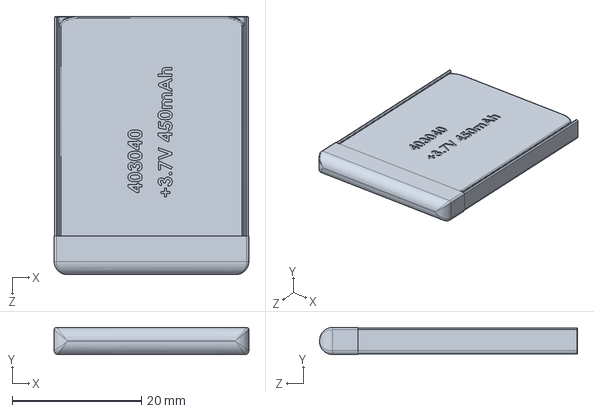
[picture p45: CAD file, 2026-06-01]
Hardware/Model/Parts/Battery-403040_450mAh.SLDPRT
30.2 x 4.20 x 40.0 mm

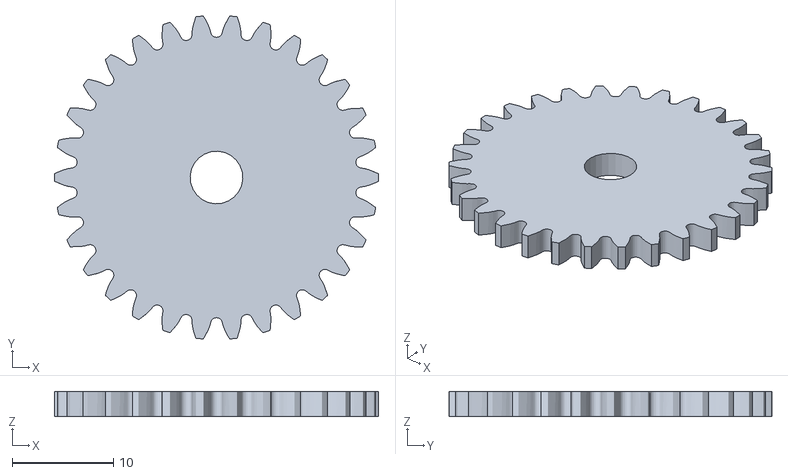
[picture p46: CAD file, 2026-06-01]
Hardware/Model/STL/Spur Gear 30 teeth.stl
32.0 x 31.9 x 2.50

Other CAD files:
Hardware/Model/Parts/N20 DC Gear Motor.step
Hardware/Model/STL/link_dom.stl
Hardware/Model/STL/Middle_part.stl
Hardware/Model/Parts/LDR.SLDPRT
Hardware/Model/Parts/2349K727_Permanently Lubricated Ball Bearing.STEP
Hardware/Model/Parts/2349K727_Permanently Lubricated Ball Bearing/2349K727_Permanently Lubricated Ball Bearing.ipt
Hardware/Model/Parts/2349K727_Permanently Lubricated Ball Bearing/OldVersions/2349K727_Permanently Lubricated Ball Bearing.0001.ipt
Hardware/Model/Parts/2WireSlipRing-2-wire-slipring/2WireSlipRing-2-wire-slipring/2WireSlipRing-2-wire-slipring.iam
Hardware/Model/Parts/2WireSlipRing-2-wire-slipring/2WireSlipRing-2-wire-slipring/negative-rotor-wire.ipt
Hardware/Model/Parts/2WireSlipRing-2-wire-slipring/2WireSlipRing-2-wire-slipring/negative-stator-wire.ipt
Hardware/Model/Parts/2WireSlipRing-2-wire-slipring/2WireSlipRing-2-wire-slipring/positive-rotor-wire.ipt
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

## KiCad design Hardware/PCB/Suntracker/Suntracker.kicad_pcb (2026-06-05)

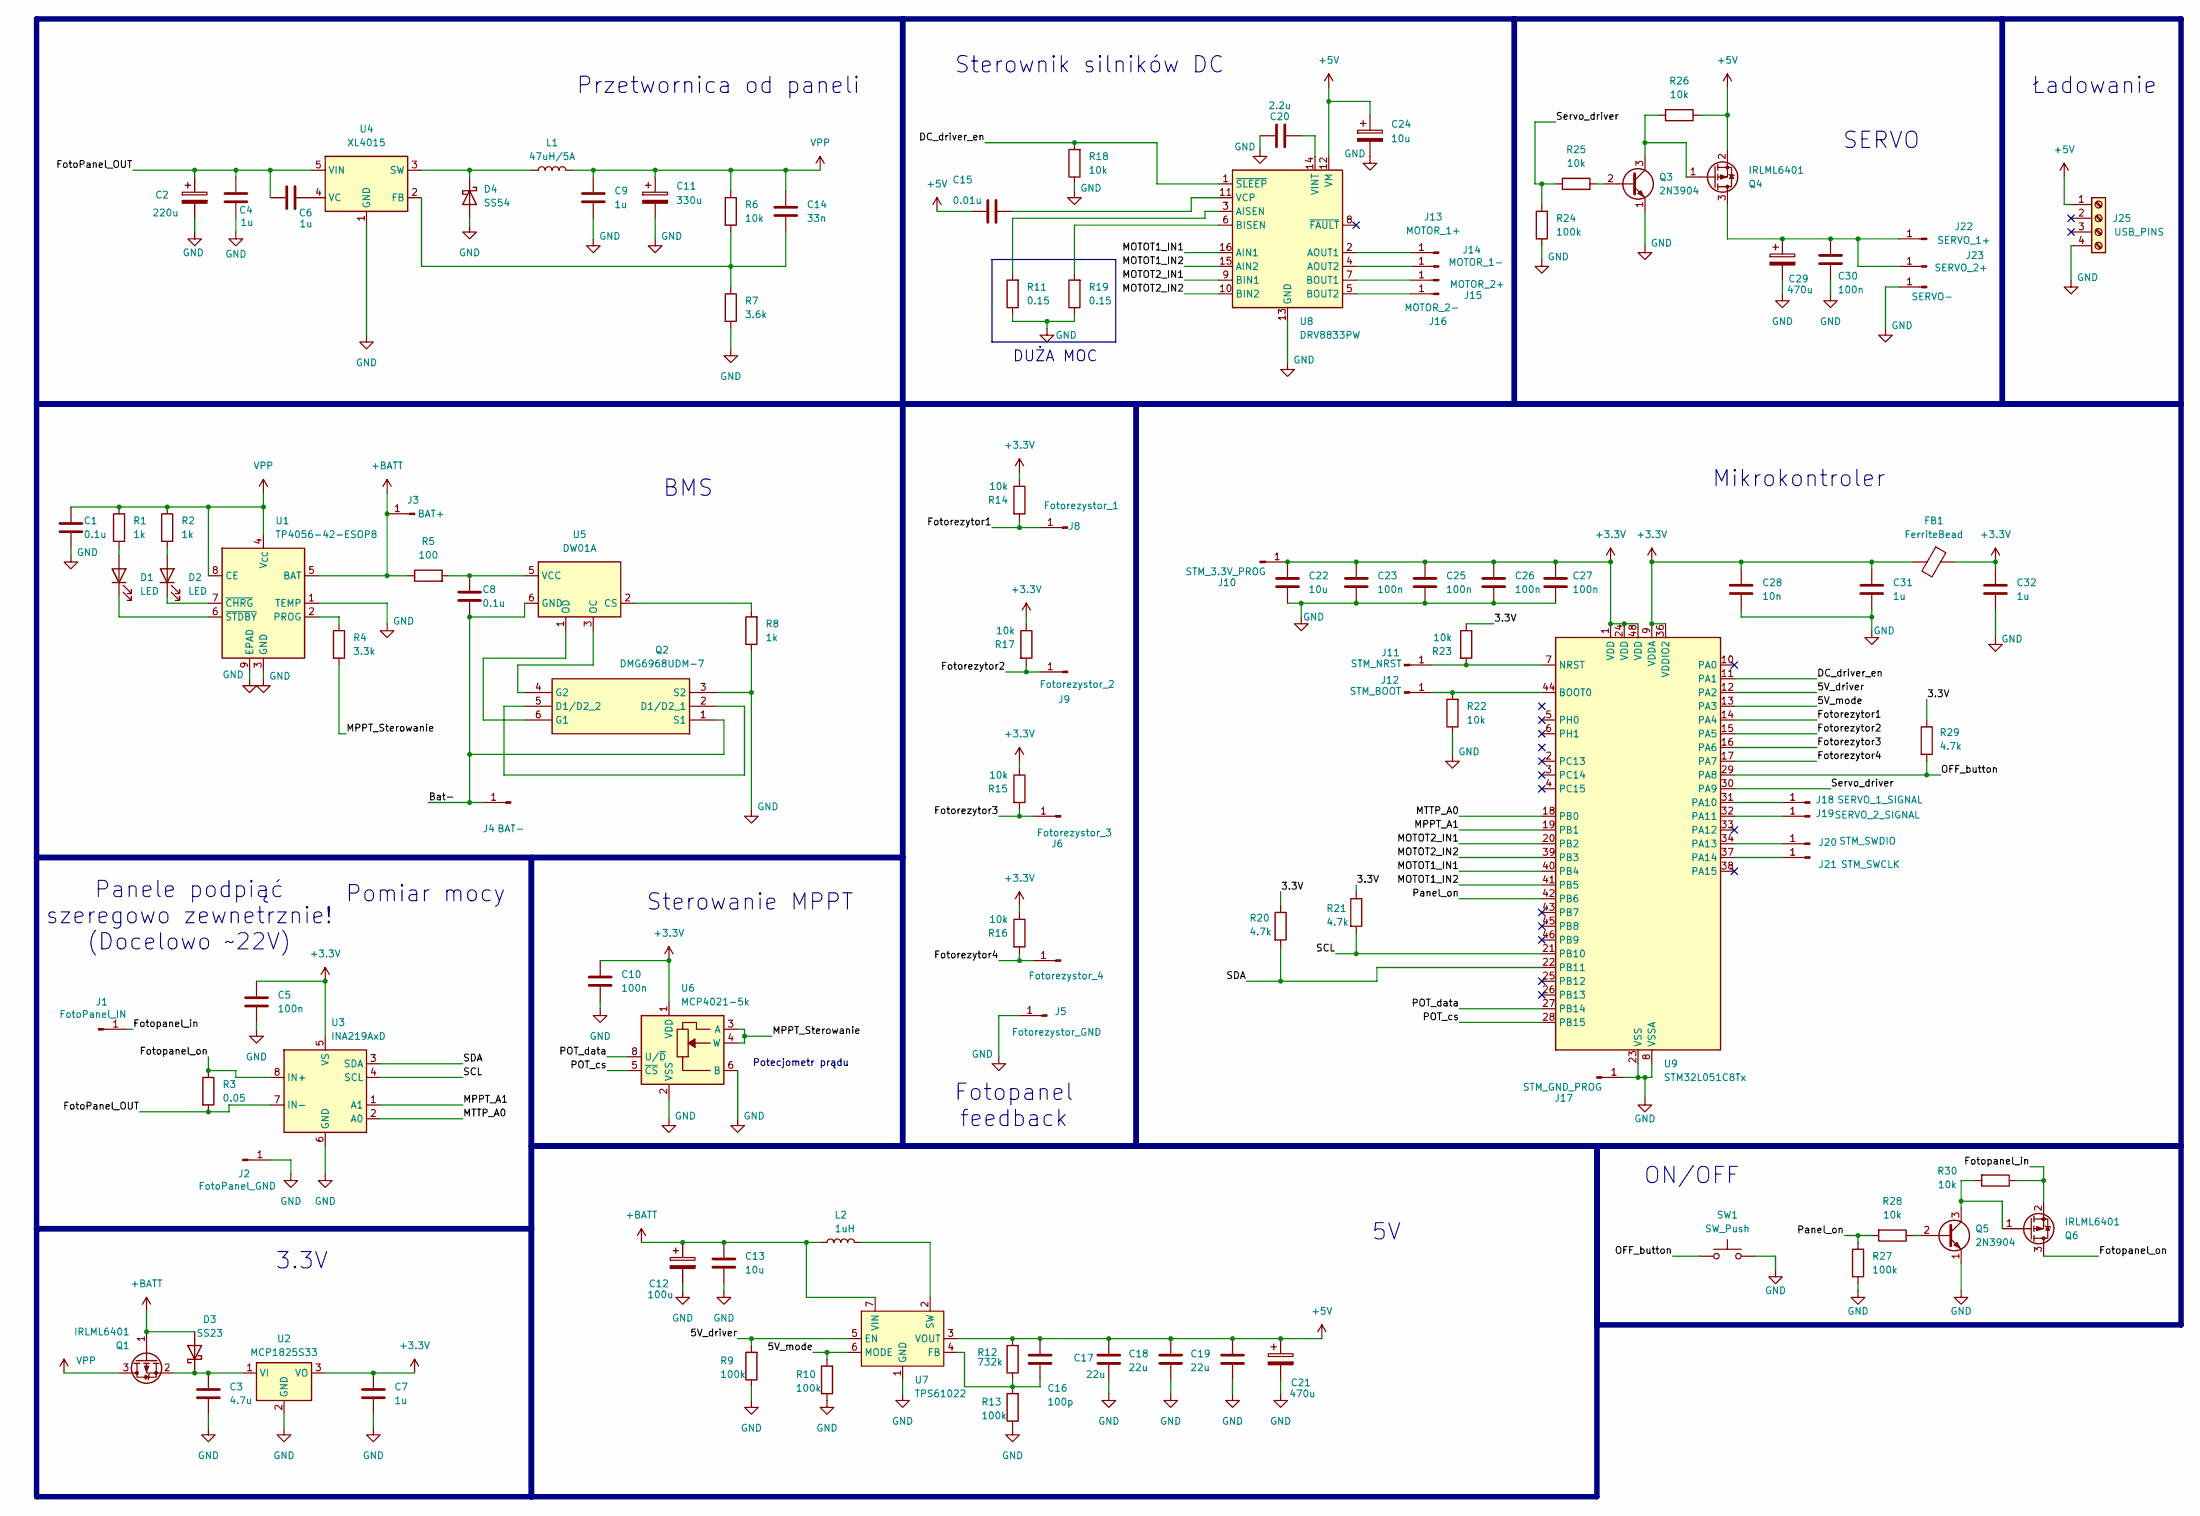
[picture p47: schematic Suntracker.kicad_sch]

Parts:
C1, C8: 0.1u; C_1206_3216Metric
C2: 220u; CP_Elec_4x5.8
C3: 4.7u; C_1206_3216Metric
C4, C6, C7, C9, C31, C32: 1u; C_1206_3216Metric
C5, C10, C23, C25, C26, C27, C30: 100n; C_1206_3216Metric
C11: 330u; CP_Elec_4x5.8
C12: 100u; CP_Elec_4x5.8
C13, C22: 10u; C_1206_3216Metric
C14: 33n; C_1206_3216Metric
C15: 0.01u; C_1206_3216Metric
C16: 100p; C_1206_3216Metric
C17, C18, C19: 22u; C_1206_3216Metric
C20: 2.2u; C_1206_3216Metric
C21, C29: 470u; CP_Elec_4x5.8
C24: 10u; CP_Elec_4x5.8
C28: 10n; C_1206_3216Metric
D1, D2: LED; LED_1206_3216Metric
D3: SS23; D_SMA
D4: SS54; D_SMC
FB1: FerriteBead; L_1206_3216Metric
J1: FotoPanel_IN; SolderWire-0.25sqmm_1x01_D0.65mm_OD1.7mm
J2: FotoPanel_GND; SolderWire-0.25sqmm_1x01_D0.65mm_OD1.7mm
J3: BAT+; SolderWire-0.25sqmm_1x01_D0.65mm_OD1.7mm
J4: BAT-; SolderWire-0.25sqmm_1x01_D0.65mm_OD1.7mm
J5: Fotorezystor_GND; SolderWire-0.25sqmm_1x01_D0.65mm_OD1.7mm
J6: Fotorezystor_3; SolderWire-0.25sqmm_1x01_D0.65mm_OD1.7mm
J7: Fotorezystor_4; SolderWire-0.25sqmm_1x01_D0.65mm_OD1.7mm
J8: Fotorezystor_1; SolderWire-0.25sqmm_1x01_D0.65mm_OD1.7mm
J9: Fotorezystor_2; SolderWire-0.25sqmm_1x01_D0.65mm_OD1.7mm
J10: STM_3.3V_PROG; SolderWire-0.25sqmm_1x01_D0.65mm_OD1.7mm
J11: STM_NRST; SolderWire-0.25sqmm_1x01_D0.65mm_OD1.7mm
J12: STM_BOOT; SolderWire-0.25sqmm_1x01_D0.65mm_OD1.7mm
J13: MOTOR_1+; SolderWire-0.25sqmm_1x01_D0.65mm_OD1.7mm
J14: MOTOR_1-; SolderWire-0.25sqmm_1x01_D0.65mm_OD1.7mm
J15: MOTOR_2+; SolderWire-0.25sqmm_1x01_D0.65mm_OD1.7mm
J16: MOTOR_2-; SolderWire-0.25sqmm_1x01_D0.65mm_OD1.7mm
J17: STM_GND_PROG; SolderWire-0.25sqmm_1x01_D0.65mm_OD1.7mm
J18: SERVO_1_SIGNAL; SolderWire-0.25sqmm_1x01_D0.65mm_OD1.7mm
J19: SERVO_2_SIGNAL; SolderWire-0.25sqmm_1x01_D0.65mm_OD1.7mm
J20: STM_SWDIO; SolderWire-0.25sqmm_1x01_D0.65mm_OD1.7mm
J21: STM_SWCLK; SolderWire-0.25sqmm_1x01_D0.65mm_OD1.7mm
J22: SERVO_1+; SolderWire-0.25sqmm_1x01_D0.65mm_OD1.7mm
J23: SERVO_2+; SolderWire-0.25sqmm_1x01_D0.65mm_OD1.7mm
J24: SERVO-; SolderWire-0.25sqmm_1x01_D0.65mm_OD1.7mm
J25: USB_PINS; TerminalBlock_MaiXu_MX126-5.0-04P_1x04_P5.00mm
L1: 47uH/5A; L_12x12mm_H4.5mm
L2: 1uH; L_SXN_SMDRI73
Q1, Q4, Q6: IRLML6401; SOT-23
Q2: DMG6968UDM-7; SOT95P285X140-6N; Manufacturer_Part_Number DMG6968UDM-7
Q3, Q5: 2N3904; TO-92_Inline
R1, R2, R8: 1k; R_1206_3216Metric
R3: 0.05; R_1206_3216Metric
R4: 3.3k; R_1206_3216Metric
R5: 100; R_1206_3216Metric
R6, R14, R15, R16, R17, R18, R22, R23, R25, R26, R28, R30: 10k; R_1206_3216Metric
R7: 3.6k; R_1206_3216Metric
R9, R10, R13, R24, R27: 100k; R_1206_3216Metric
R11, R19: 0.15; R_1206_3216Metric
R12: 732k; R_1206_3216Metric
R20, R21, R29: 4.7k; R_1206_3216Metric
SW1: SW_Push; SW_Push_1P1T_NO_E-Switch_TL3301NxxxxxG
U1: TP4056-42-ESOP8; SOIC-8-1EP_3.9x4.9mm_P1.27mm_EP2.41x3.3mm_ThermalVias
U2: MCP1825S33; SOT-223-3_TabPin2
U3: INA219AxD; SOIC-8_3.9x4.9mm_P1.27mm
U4: XL4015; TO-263-5_TabPin3
U5: DW01A; SOT-23-6
U6: MCP4021-5k; MSOP-8_3x3mm_P0.65mm
U7: TPS61022; Texas_RWU0007A_VQFN-7_2x2mm_P0.5mm
U8: DRV8833PW; TSSOP-16_4.4x5mm_P0.65mm
U9: STM32L051C8Tx; LQFP-48_7x7mm_P0.5mm

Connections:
+3.3V: C5.1, C7.1, C10.1, C22.1, C23.1, C25.1, C26.1, C27.1, C28.1, C31.1, C32.1, FB1.1, FB1.2, J10.1 (Pin_1_1), R14.1, R15.1, R16.1, R17.1, U2.3 (VO), U3.5 (VS), U6.1 (VDD), U9.1 (VDD), U9.9 (VDDA), U9.24 (VDD), U9.36 (VDDIO2), U9.48 (VDD)
+5V: C15.1, C16.2, C17.2, C18.2, C19.2, C21.1, C24.1, J25.1, Q4.2 (S), R12.2, R26.1, U7.3 (VOUT), U8.12 (VM)
+BATT: C12.1, C13.2, D3.2 (A), J3.1 (Pin_1_1), L2.1, Q1.1 (G), R5.1, U1.5 (BAT), U7.7 (VIN)
/3.3V: R20.1, R21.1, R23.1, R29.1
/5V_driver: R9.2, U7.5 (EN), U9.12 (PA2)
/5V_mode: R10.2, U7.6 (MODE), U9.13 (PA3)
/Bat-: C8.2, J4.1 (Pin_1_1), Q2.1 (S1), U5.6 (GND)
/DC_driver_en: R18.2, U8.1 (~SLEEP), U9.11 (PA1)
/FotoPanel_OUT: C2.1, C4.2, C6.1, R3.2, U3.7 (IN-), U4.5 (VIN)
/Fotopanel_in: J1.1 (Pin_1_1), Q6.2 (S), R30.1
/Fotopanel_on: Q6.3 (D), R3.1, U3.8 (IN+)
/Fotorezytor1: J8.1 (Pin_1_1), R14.2, U9.14 (PA4)
/Fotorezytor2: J9.1 (Pin_1_1), R17.2, U9.15 (PA5)
/Fotorezytor3: J6.1 (Pin_1_1), R15.2, U9.16 (PA6)
/Fotorezytor4: J7.1 (Pin_1_1), R16.2, U9.17 (PA7)
/MOTOT1_IN1: U8.16 (AIN1), U9.40 (PB4)
/MOTOT1_IN2: U8.15 (AIN2), U9.41 (PB5)
/MOTOT2_IN1: U8.9 (BIN1), U9.20 (PB2)
/MOTOT2_IN2: U8.10 (BIN2), U9.39 (PB3)
/MPPT_A1: U3.1 (A1), U9.19 (PB1)
/MPPT_Sterowanie: R4.2, U6.3 (A), U6.4 (W)
/MTTP_A0: U3.2 (A0), U9.18 (PB0)
/OFF_button: R29.2, SW1.1, U9.29 (PA8)
/POT_cs: U6.5 (~CS), U9.28 (PB15)
/POT_data: U6.8 (U/~D), U9.27 (PB14)
/Panel_on: R27.2, R28.2, U9.42 (PB6)
/SCL: R21.2, U3.4 (SCL), U9.21 (PB10)
/SDA: R20.2, U3.3 (SDA), U9.22 (PB11)
/Servo_driver: R24.2, R25.2, U9.30 (PA9)
GND: C1.2, C2.2, C3.2, C4.1, C5.2, C7.2, C9.2, C10.2, C11.2, C12.2, C13.1, C17.1, C18.1, C19.1, C20.1, C21.2, C22.2, C23.2, C24.2, C25.2, C26.2, C27.2, C28.2, C29.2, C30.2, C31.2, C32.2, D4.2 (A), J2.1 (Pin_1_1), J5.1 (Pin_1_1), J17.1 (Pin_1_1), J24.1 (Pin_1_1), J25.4, Q2.3 (S2), Q3.1 (E), Q5.1 (E), R7.2, R8.1, R9.1, R10.1, R11.1, R13.1, R18.1, R19.1, R22.1, R24.1, R27.1, SW1.2, U1.1 (TEMP), U1.3 (GND), U1.9 (EPAD), U2.2 (GND), U3.6 (GND), U4.1 (GND), U6.2 (VSS), U6.6 (B), U7.1 (GND), U8.13 (GND), U9.8 (VSSA), U9.23 (VSS), U9.35 (VSS), U9.47 (VSS)
unnamed: D1.2 (A), R1.2
unnamed: D1.1 (K), U1.6 (~STDBY)
unnamed: D2.2 (A), R2.2
unnamed: D2.1 (K), U1.7 (~CHRG)
unnamed: C3.1, D3.1 (K), Q1.2 (S), U2.1 (VI)
unnamed: D4.1 (K), L1.1, U4.3 (SW)
unnamed: J11.1 (Pin_1_1), R23.2, U9.7 (NRST)
unnamed: J12.1 (Pin_1_1), R22.2, U9.44 (BOOT0)
unnamed: J13.1 (Pin_1_1), U8.2 (AOUT1)
unnamed: J14.1 (Pin_1_1), U8.4 (AOUT2)
unnamed: J15.1 (Pin_1_1), U8.7 (BOUT1)
unnamed: J16.1 (Pin_1_1), U8.5 (BOUT2)
unnamed: J18.1 (Pin_1_1), U9.31 (PA10)
unnamed: J19.1 (Pin_1_1), U9.32 (PA11)
unnamed: J20.1 (Pin_1_1), U9.34 (PA13)
unnamed: J21.1 (Pin_1_1), U9.37 (PA14)
unnamed: C29.1, C30.1, J22.1 (Pin_1_1), J23.1 (Pin_1_1), Q4.3 (D)
unnamed: Q2.2 (D1/D2_1), Q2.5 (D1/D2_2)
unnamed: Q2.6 (G1), U5.1 (OD)
unnamed: Q2.4 (G2), U5.3 (OC)
unnamed: Q3.2 (B), R25.1
unnamed: Q3.3 (C), Q4.1 (G), R26.2
unnamed: Q5.2 (B), R28.1
unnamed: Q5.3 (C), Q6.1 (G), R30.2
unnamed: R4.1, U1.2 (PROG)
unnamed: C14.2, R6.2, R7.1, U4.2 (FB)
unnamed: C6.2, U4.4 (VC)
unnamed: R8.2, U5.2 (CS)
unnamed: C8.1, R5.2, U5.5 (VCC)
unnamed: C16.1, R12.1, R13.2, U7.4 (FB)
unnamed: L2.2, U7.2 (SW)
unnamed: R11.2, U8.3 (AISEN)
unnamed: R19.2, U8.6 (BISEN)
unnamed: C15.2, U8.11 (VCP)
unnamed: C20.2, U8.14 (VINT)
VPP: C1.1, C9.1, C11.1, C14.1, L1.2, Q1.3 (D), R1.1, R2.1, R6.1, U1.4 (V_{CC}), U1.8 (CE)

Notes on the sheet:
DUŻA MOC
Mikrokontroler
Fotopanel feedback
ON/OFF
Sterownik silników DC
Sterowanie MPPT
3.3V
Przetwornica od paneli
BMS
Pomiar mocy
Panele podpiąć szeregowo zewnetrznie! (Docelowo ~22V)
Potecjometr prądu
SERVO
Ładowanie

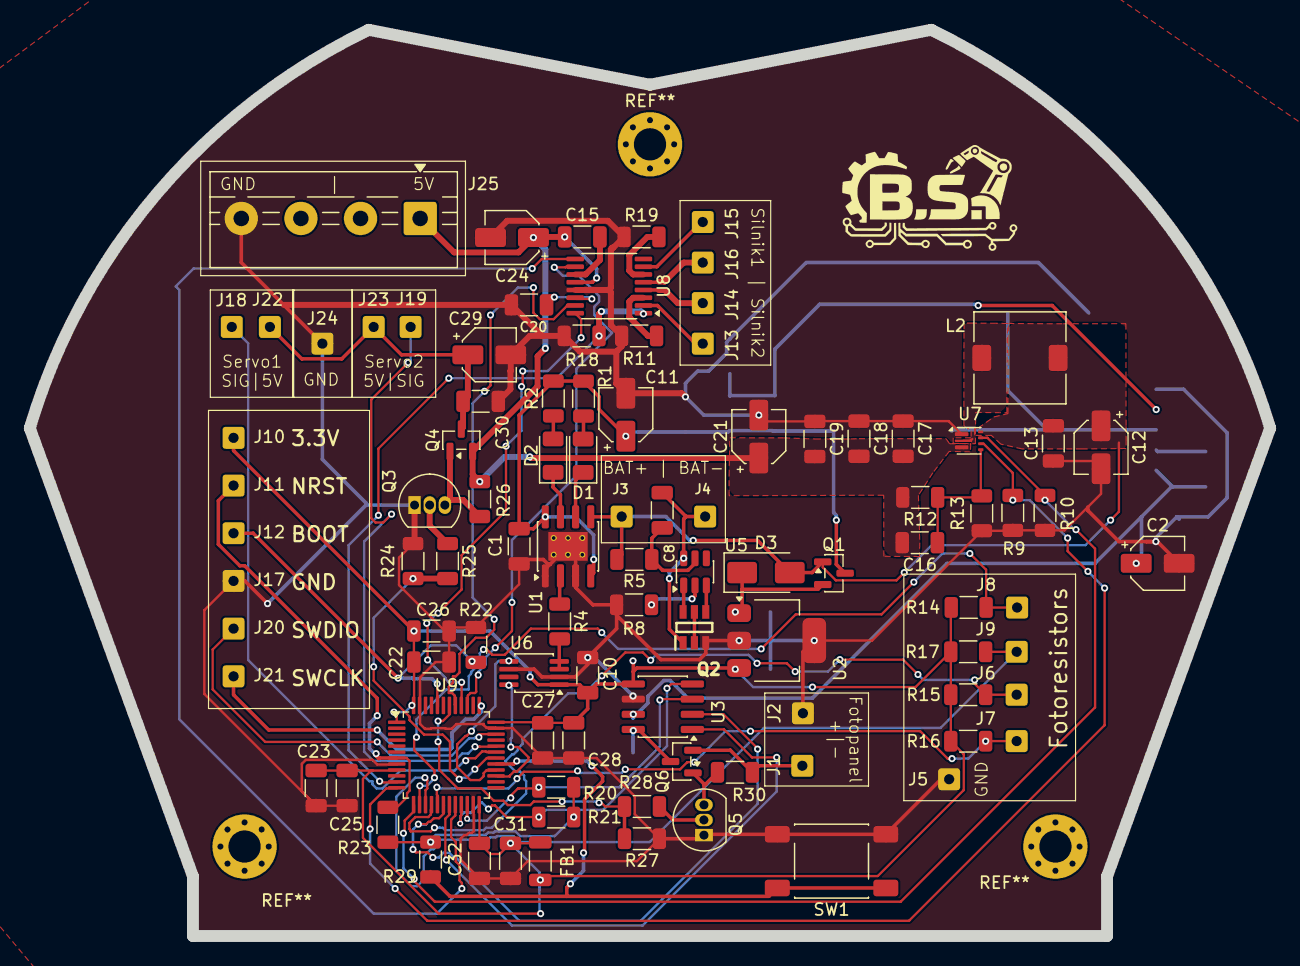
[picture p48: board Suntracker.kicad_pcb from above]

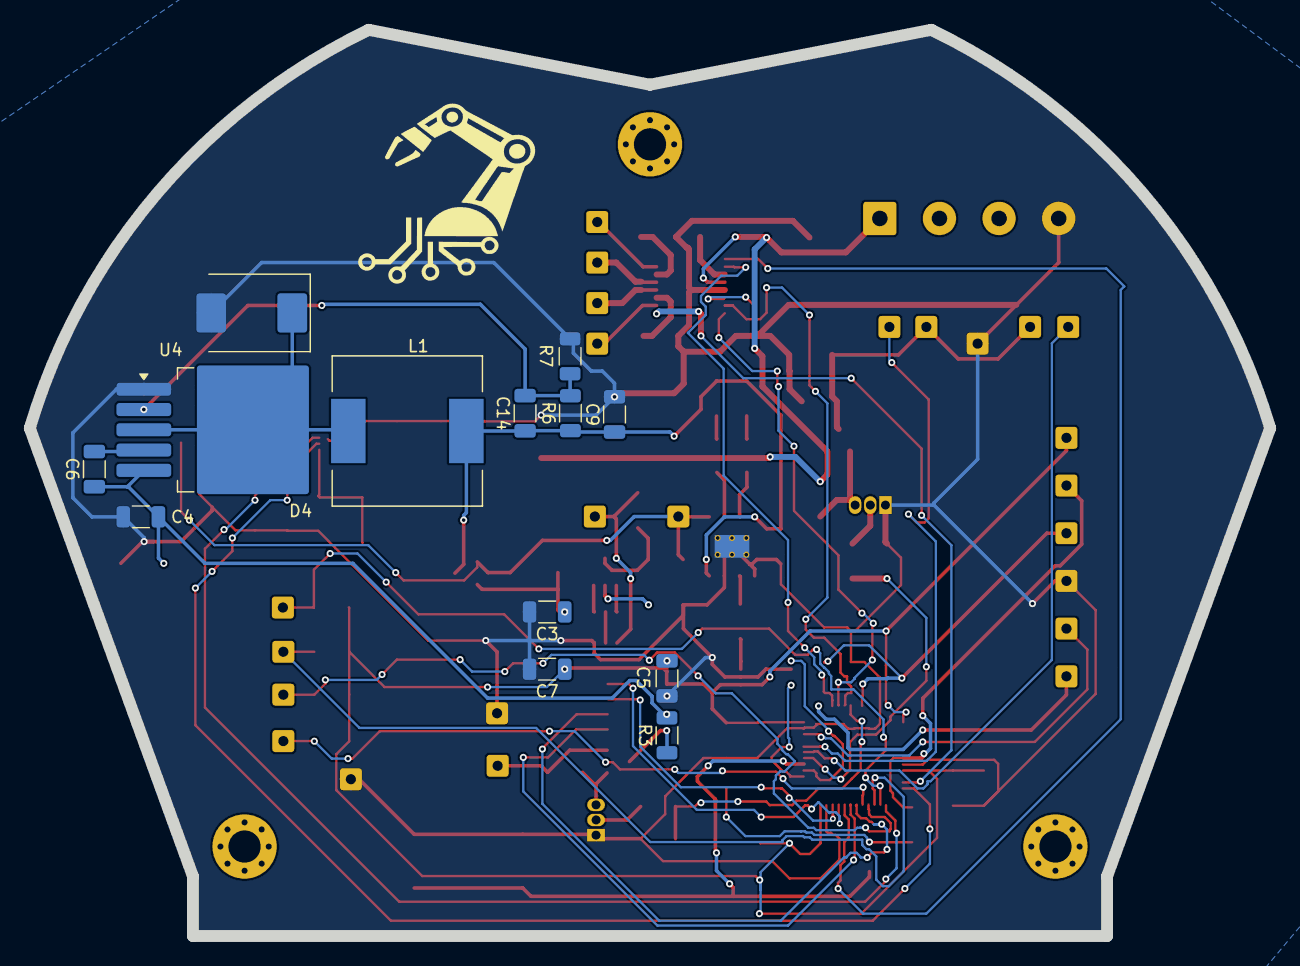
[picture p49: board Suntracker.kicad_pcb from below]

Board: 2 copper layers, 104.0 x 76.0 mm, 110 parts (13 on the bottom side), 66 nets.

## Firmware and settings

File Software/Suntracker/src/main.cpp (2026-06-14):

#include <Arduino.h>
#include <Wire.h>
#include "Pins.h"
#include "General.h"
#include "Motors.h"
#include "MPPT.h"
#include "Photorezistors.h"
#include "INA219.h"
#include "MCP40xx.h"
#include "Interrupt.h"
#include "STM32LowPower.h"
#include "STM32RTC.h"

// External objects for RTC, power monitoring, and digital potentiometer
extern STM32RTC &rtc;
extern INA219 ina219;
extern MCP40xx mcp40xx;
extern HardwareTimer timer1;

// Initialize all hardware: pins, I2C communication, and interrupt handlers
void setup()
{
  Pinout_init();          // Configure GPIO pins
  Wire_Init();            // Initialize I2C communication
  Interrupts_init();      // Set up interrupt handlers

}

// Main program loop - handles state machine and interrupts
void loop()
{
  // Handle power button press
  if (powerButtonFlag)
  {
    noInterrupts();       // Disable interrupts to safely modify flags
    powerButtonFlag = false;
    interrupts();         // Re-enable interrupts

    // Toggle power state and set appropriate initial state
    if (Power == OFF)
    {
      Power = ON;           // Turn system ON
      Initial_State = START;  // Start initialization sequence
      Timer_counter = 0;
    }
    else
    {
      Power = OFF;          // Turn system OFF
      Initial_State = FOLD;  // Fold panel before sleeping
    }
  }

  // Handle periodic wake-up from sleep (every 60 seconds)
  if (wakeTickFlag)
  {
    noInterrupts();       // Disable interrupts to safely modify flags
    wakeTickFlag = false;
    interrupts();         // Re-enable interrupts

    if (Initial_State == Sleep && Power == ON)
    {
      Timer_counter++;    // Increment wake counter

      // After 15 wake cycles (~15 minutes), re-optimize panel position
      if (Timer_counter >= 15)
      {
        Initial_State = Harvest_update;  // Update optimal panel position
        Timer_counter = 0;
      }
      else
      {
        Initial_State = Harvest;  // Continue normal operation
      }
    }
  }

  // State machine - manages system operation modes
  switch (Initial_State)
  {
  case START:  // Initialize system and find optimal panel position
    System_Start();
    if (Initial_State == START)
      Initial_State = Harvest;  // Move to harvesting mode
    break;

  case Harvest_update:  // Re-optimize panel position periodically
    Harvest_Update();
    if (Initial_State == Harvest_update)
      Initial_State = Harvest;  // Return to normal harvesting
    break;

  case Harvest:  // Normal operation - track sun and optimize power
    MPPT_menager();  // Run maximum power point tracking algorithm
    if (Initial_State == Harvest)
      Initial_State = Sleep;  // Go to sleep after harvesting
    break;

  case FOLD:  // Fold panel to safe position
    System_Fold();
    if (Initial_State == FOLD)
      Initial_State = Sleep;  // Go to sleep after folding
    break;

  case Sleep:  // Low power sleep mode
    System_Sleep();  // Enter deep sleep and wait for wake-up
    break;
  }
}

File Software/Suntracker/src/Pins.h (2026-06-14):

#pragma once
#include <Arduino.h>

// ===== DIGITAL POTENTIOMETER (for MPPT load resistance) =====
const uint16_t POT_data = PB14;  // Data pin for digital potentiometer
const uint16_t POT_cs = PB15;    // Chip select pin for digital potentiometer

// ===== MPPT FEEDBACK ANALOG INPUTS =====
const uint16_t MPPT_A0 = PB0;    // MPPT feedback input 0
const uint16_t MPPT_A1 = PB1;    // MPPT feedback input 1

// ===== LIGHT SENSORS (4 photorezistors for sun position detection) =====
const uint16_t Photorezistor_1 = PA4;  // Top-left
const uint16_t Photorezistor_2 = PA5;  // Top-right
const uint16_t Photorezistor_3 = PA6;  // Bottom-left
const uint16_t Photorezistor_4 = PA7;  // Bottom-right

// ===== MOTOR 1 CONTROL PINS (Horizontal rotation) =====
const uint16_t Motor1_in1 = PB4;  // Motor 1 direction control IN1
const uint16_t Motor1_in2 = PB5;  // Motor 1 direction control IN2

// ===== MOTOR 2 CONTROL PINS (Vertical tilt) =====
const uint16_t Motor2_in1 = PB2;  // Motor 2 direction control IN1
const uint16_t Motor2_in2 = PB3;  // Motor 2 direction control IN2

// ===== SERVO CONTROL PINS =====
const uint16_t Servo_power_enable = PA9;   // Servo power enable
const uint16_t Servo_signal = PA10;        // Servo PWM signal (main servo)
const uint16_t Servo_2_signal = PA11;      // Servo PWM signal (secondary servo)

// ===== POWER ENABLE/CONTROL PINS =====
const uint16_t Motor_driver_enable = PA1;  // Enable main motor driver
const uint16_t Logic_5V_enable = PA2;      // Enable 5V logic power supply
const uint16_t Logic_5V_mode = PA3;        // Select 5V logic mode (output level)
const uint16_t Panel_enable = PB6;         // Enable solar panel output

// ===== USER INPUT =====
const uint16_t POWER_ON = PA8;  // Power button input (active LOW)

// ===== COMMUNICATION =====
const uint32_t PIN_I2C_SCL = PB10;  // I2C clock line (for power monitor)
const uint32_t PIN_I2C_SDA = PB11;  // I2C data line (for power monitor)

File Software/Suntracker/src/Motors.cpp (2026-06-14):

#include "Motors.h"
#include <Arduino.h>
#include <Servo.h>
#include "Pins.h"
#include <math.h>

Servo servo;  // Servo object for tilt control

// Set servo to specific angle
// Adjusts angle by gear ratio and converts to PWM microseconds
void Set_Servo_angle(float angle)
{
    angle *= Servo_przekladnia;  // Apply gear reduction
    servo.attach(Servo_signal);  // Attach servo to PWM pin
    int pwmValue = map(angle, 0, 180, 1000, 2000);  // Convert to microseconds
    servo.writeMicroseconds(pwmValue);  // Send PWM signal
}

// Set motor PWM value and direction
// direction: true = forward, false = backward
// pwm: 0-255 PWM value
void Motor1_SetPWM(bool direction, int pwm)
{
  pwm = constrain(pwm, 0, 255);  // Limit PWM to valid range

  if (direction)  // Forward direction
  {
    analogWrite(Motor1_in1, pwm);  // Apply PWM to IN1
    digitalWrite(Motor1_in2, LOW);  // Disable IN2
  }
  else  // Backward direction
  {
    digitalWrite(Motor1_in1, LOW);  // Disable IN1
    analogWrite(Motor1_in2, pwm);  // Apply PWM to IN2
  }
}

// Stop motor completely (both pins LOW)
void Motor1_Stop()
{
  digitalWrite(Motor1_in1, LOW);
  digitalWrite(Motor1_in2, LOW);
}

// Rotate motor to specific angle
// Uses 3-phase speed profile: start, constant, stop (for "smooth" acceleration/deceleration)
void Set_Motor1_Direction(float angle)
{
  // No movement needed
  if (angle == 0)
  {
    Motor1_Stop();
    return;
  }

  // Determine direction and magnitude
  bool direction = angle > 0;  // True = clockwise, False = counter-clockwise
  float angleAbs = fabs(angle);

  // Calculate required motor revolutions
  float revolutions = angleAbs / 360.0f;

  // Calculate effective motor speed
  float avgPWM = (speed_start + speed_const + speed_stop) / 3.0f;
  float pwmFactor = avgPWM / 255.0f;
  float effectiveRPS = (MOTOR1_speed / 60.0f) * MOTOR1_przekladnia * pwmFactor;  // Revolutions per second

  if (effectiveRPS <= 0)
    return;

  // Calculate total working time and time for each phase
  float Working_time = revolutions / effectiveRPS;
  unsigned long partTime_ms = (unsigned long)((Working_time / 3.0f) * 1000.0f);  // 1/3 for each phase

  // Phase 1: Acceleration (low speed)
  Motor1_SetPWM(direction, speed_start);
  delay(partTime_ms);

  // Phase 2: Constant speed (cruise)
  Motor1_SetPWM(direction, speed_const);
  delay(partTime_ms);

  // Phase 3: Deceleration (low speed)
  Motor1_SetPWM(direction, speed_stop);
  delay(partTime_ms);

  // Stop motor
  Motor1_Stop();
}
// Move motor 2 (vertical tilt) for specified distance
// Calculates time based on motor speed and distance
void Set_Motor2_Direction(float distance)
{
  // No movement needed
  if (distance == 0)
  {
    digitalWrite(Motor2_in1, LOW);
    digitalWrite(Motor2_in2, LOW);
    return;
  }

  // Determine direction and magnitude
  bool direction = distance > 0;  // True = up, False = down
  float distanceAbs = fabs(distance);

  // Calculate linear speed (mm/s)
  float linearSpeed = (MOTOR2_speed / 60.0f) * 10.0f;  // Convert RPM to mm/s
  float Working_time = distanceAbs / linearSpeed;  // Time needed (seconds)

  // Set direction and start motor
  digitalWrite(Motor2_in1, direction);   // Set direction IN1
  digitalWrite(Motor2_in2, !direction);  // Set opposite direction IN2

  // Wait for movement to complete
  delay((unsigned long)(Working_time * 1000.0f));

  // Stop motor
  digitalWrite(Motor2_in1, LOW);
  digitalWrite(Motor2_in2, LOW);
}

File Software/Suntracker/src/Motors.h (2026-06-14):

#pragma once

#define SERVO_MIN_ANGLE 0      // Minimum servo angle (degrees)
#define SERVO_MAX_ANGLE 180    // Maximum servo angle (degrees)

// External gear ratio - converts motor rotation to panel angle
#define MOTOR1_przekladnia ((1.0f / 6.0f))  // Gear reduction ratio (1:6)
// Motor speed at 5V (reduced from 100 RPM at 6V)
#define MOTOR1_speed   83       // Speed in RPM at 5V

// Motor speed at 5V (reduced from 400 RPM at 6V)
#define MOTOR2_speed   342      // Speed in RPM at 5V

#define Servo_przekladnia (17.0f / 30.0f)  // Servo gear reduction ratio

#define speed_start 100   // Initial speed (PWM value for acceleration)
#define speed_const 240   // Constant/cruise speed (PWM value)
#define speed_stop 20     // Final speed (PWM value for deceleration)

// Function declarations
void Set_Servo_angle(float angle);           // Set servo to specific angle
void Set_Motor1_Direction(float angle);      // Rotate panel horizontally
void Set_Motor2_Direction(float distance);   // Tilt panel vertically

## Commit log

2026-06-01 Add Inventor simulation images and video
    Add visual assets for the Inventor simulation: five PNG frames (kolizja_1.png, kolizja_2.png, kolizja_3-1.png, kolizja_3-2.png, kolizja_4.png) and a sequence video (sequence.avi) under Simulations/Inventor. These files document a collision sequence for visualization, demos, and documentation.
2026-06-01 Add Harvest_Update and main state machine
    Introduce a Harvest_Update routine and a simple state machine to manage startup, harvesting, folding and sleep cycles.
    Changes:
    - Include Photorezistors.h.
    - Update System_Start to find/set an optimal panel position before initializing MPPT.
    - Add Harvest_Update() which powers the panel, finds optimal position and starts MPPT.
    - Modify System_Sleep() to disable 5V logic power instead of directly toggling panel power.
    - Expose Harvest_Update() in General.h.
    - Add a state enum and Initial_State in main.cpp and implement the loop() as a state machine (START, Harvest_update, Harvest, FOLD, Sleep).
    Notes: contains TODOs/comments to replace the if-chain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
    [General.cpp, main.cpp]
2026-06-01 Remove System_Init and fix System_Fold call
    Remove the call to System_Init() from System_Start() and delete its prototype from General.h, indicating the init routine is no longer used. Also correct a typo in main.cpp by changing system_Fold() to System_Fold() so the call matches the proper function name. These changes align declarations and callers and prevent references to a removed init function.
    [General.cpp, main.cpp]
2026-06-02 Infer motor direction from sign; update callers
    Refactor motor API to remove explicit direction boolean: Set_Motor1_Direction and Set_Motor2_Direction now take a signed float (angle/distance) and determine direction from the sign. Updated function implementations and prototypes in Motors.cpp/.h and fixed all call sites in General.cpp and Photorezistors.cpp to pass a single signed value (positive for forward, negative for reverse). Also refactored the main loop state handling in main.cpp from chained if/else to a switch/case with proper breaks to clarify flow and transitions. Files changed: General.cpp, Motors.cpp, Motors.h, Photorezistors.cpp, main.cpp.
    [General.cpp, Motors.cpp, Motors.h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]
2026-06-02 Add power-on interrupt and state handler
    Introduce a hardware interrupt for the POWER_ON pin and a corresponding interrupt() routine that wakes the system: when in Sleep it moves to START, otherwise it sets the state to FOLD. attachInterrup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
2026-06-03 Use signed position and refine motor stepping
    Change position type to signed (uint16_t -> int16_t) in General.cpp to allow negative/directional offsets. Add <math.h> include in Motors.cpp. Fix Motors.h parameter order/names to match intended semantics (Set_Motor1_Direction uses angle, Set_Motor2_Direction uses distance). Revise Find_optimal_position logic and comments in Photorezistors.cpp: explicitly test positive and negative steps, revert on worsening readings, and ensure steps use the correct sign so the panel returns to the start when neither direction improves voltage.
    [General.cpp, Motors.cpp, Motors.h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]
2026-06-03 Add power state and hardware timer
    Introduce power management and timer-driven harvest updates: make Initial_State volatile, add Power_state enum and Power flag, and add Harvest_time and Timer_counter. Replace generic interrupt() with PowerButton_ISR to handle power button toggles and implement Harvest_Update_interrupt to advance harvest states based on a HardwareTimer. Instantiate HardwareTimer timer1 (TIM2) and configure it in setup (setOverflow, attachInterrupt, refresh/resume), and update attachInterrupt call to use the new ISR.
    [main.cpp]
2026-06-03 Add interrupt module and initialization
    Introduce Interrupt.h/cpp to centralize power/state enums, timer and ISRs (PowerButton_ISR, Harvest_Update_interrupt) and initialize hardware interrupts. Add Pinout_init and Wire_Init (General.cpp/h) to configure GPIOs and I2C, and include Wire in General.cpp. Update main.cpp to use the new init helpers (Pinout_init, Wire_Init, Interrupts_Init), extern the timer, and simplify setup. Modify Harvest_Update/System sequences to power required subsystems before operations and make loop state transitions defensive to avoid race conditions.
    [General.cpp, main.cpp]
2026-06-03 Add STM32 RTC/LowPower and integrate sleep
    Introduce STM32 low-power and RTC support and integrate it into the system sleep flow. Added STM32LowPower.{h,cpp}, STM32RTC.{cpp,h}, low_power.c/.h and rtc.c/.h (ST licensing headers included) and a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
2026-06-03 Use wake flag for power-button ISR
    Refactor interrupt handling so the ISR only sets a wake flag and deferred handling runs in normal context. Changes include:
    - Include interrupt.h where needed and expose shared symbols.
    - Add volatile Button_wakeup_flag and set it in PowerButton_ISR (no heavy logic in ISR).
    - Add Handle_Power_Button() that performs the previous ISR state transitions (Power/Initial_State/Timer_counter).
    - In System_Sleep(), clear Button_wakeup_flag before sleep, then after deepSleep call Handle_Power_Button() if the flag was set, otherwise call Harvest_Update_interrupt().
    - Move/declare shared timer and state globals (Timer_counter, Initial_State, Power) as externs in Inter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
2026-06-03 Move init calls and add wakeup handler
    Move Pinout_init() and Wire_Init() to the start of setup() (before RTC/LowPower init) and adjust brace style. Remove the late Interrupt_Init() call. In loop(), add a Button_wakeup_flag check that disables interrupts, clears the flag, re-enables interrupts and calls Handle_Power_Button() before entering the state switch to safely handle power-button wakeups and avoid race conditions.
    [main.cpp]
2026-06-03 Disable interrupts when clearing wakeup flag
    In System_Sleep(), clear Button_wakeup_flag inside noInterrupts()/interrupts() to avoid race conditions with interrupt handlers before calling Handle_Power_Button(). This ensures the wakeup flag is reset atomically and prevents spurious re-entry while handling the power button.
    [General.cpp]
2026-06-04 Add datasheets and Suntracker backup
    Add multiple component datasheets and project documentation. This commit adds PDFs for 2N3903, DMG6968UDM, DRV8833, DW01A, INA219, IRLML6401, MCP1825, MG90S, STM32L051X6, TP4056, TPS61022, XL4015, th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
2026-06-04 Refactor interrupt flags & add sunlight safety
    Make ISR routines minimal and expose new flags: replace Button_wakeup_flag with powerButtonFlag and add wakeTickFlag (set in ISR) so the main loop does deferred processing. Move Timer_counter/volatile declarations into the header and remove Interrupt_Init; update main loop to handle power on/off, wake ticks (increment Timer_counter and transition between Harvest/Harvest_update/Harvest states), and fold on low-light condition. Add Critical_Sunlight flag in Photorezistors (set when ambient < MIN_LIGHT_LEVEL) and fold the system when critical while powered. Also remove the unused Handle_Power_Button calls and simplify state transition checks.
    [Photorezistors.cpp, Photorezistors.h, main.cpp]
2026-06-04 Use panel voltage threshold for critical sunlight
    Add MIN_PANEL_START_VOLTAGE macro and change sun-tracking logic to decide Critical_Sunlight based on measured panel voltage. Find_optimal_position now clears the flag, reads the average panel voltage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
2026-06-04 Rename Button_wakeup_flag to powerButtonFlag
    Replace uses of Button_wakeup_flag with powerButtonFlag and remove the duplicate volatile declaration. General.cpp now initializes and checks powerButtonFlag (clearing it inside noInterrupts/interrupts before handling the power button). Interrupt.cpp drops the old Button_wakeup_flag declaration to avoid a duplicate symbol and keep the flag consistently defined.
    [General.cpp]
2026-06-04 Make MPPT_Init return status and handle shutdown
    Change MPPT_Init from void to bool and return false when Critical_Sunlight is detected to avoid initializing the MPPT in unsafe conditions. Update MPPT.h prototype and MPPT.cpp (added Interrupt.h and Photorezistors.h, return true on success). Update callers in General.cpp (System_Start, Harvest_Update) and main.cpp to check MPPT_Init() and set Initial_State = FOLD and return early when initialization fails. Also remove an unused Button_wakeup_flag declaration from Interrupt.h.
    [General.cpp, MPPT.h, main.cpp]
2026-06-04 Move RTC and wakeup setup to Interrupts_init
    Centralize RTC and low-power wakeup configuration in a new Interrupts_init() function within Interrupt.cpp and expose rtc as an extern in headers/main. Added Button_wakeup_flag and its extern declaration. Interrupts_init() sets the RTC clock source, initializes LowPower, and attaches the power button wakeup ISR. main.cpp now calls Interrupts_init() and no longer initializes the RTC/LowPower directly. Also removed an early MPPT_Init() failure check from main.cpp. Small includes and forward declarations were added to support these changes.
    [main.cpp]
2026-06-05 Add CAD hardware parts; update assembly
    Add multiple CAD part files (STEP and IPT) for fasteners and hardware: 92000A013, 92000A017, 92000A113 screws; 94459A110 heat-set inserts; 98886A826 PEEK hex nut; a 6x6 button; plus various OldVersio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
    [92000A013_Passivated 18-8 Stainless Steel Pan Head Phillips Screws.STEP, 92000A013_Passivated 18-8 Stainless Steel Pan Head Phillips Screws.ipt, 92000A017_Pass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]
2026-06-05 Update motor speeds; add BOM, models & PCB lock
    Adjust motor speed constants and add project artifacts: Motors.h - change MOTOR1_speed from 120 to 100 RPM and MOTOR2_speed from 120 to 400 RPM. Add BOM/BOM.xlsx and its temp file (~$BOM.xlsx). Replace Hardware/Model/OldVersions/main.0046.iam with main.0047.iam and update Hardware/Model/main.iam. Add KiCad lock file Hardware/PCB/Suntracker/~Suntracker.kicad_pro.lck. These changes update runtime motor configuration and include new BOM/model files and a PCB project lock.
    [BOM.xlsx, main.0046.iam]
2026-06-05 Cleaning be4 final documentation
    [Suntracker.kicad_pcb]
2026-06-06 Update BOM spreadsheet and Suntracker PDF
    Replace BOM/BOM.xlsx and Documentation/Suntracker.pdf with updated binary versions. The spreadsheet updates the bill of materials and the PDF refreshes the Suntracker documentation; no source code changes.
    [BOM.xlsx]
2026-06-06 Add simulations and update motor parameters
    Add Inventor and LTspice simulation assets and update motor configuration.
    - Added Simulations/Inventor/README.md and Simulations/Ltspice/README.md describing collision analysis and animation of the PV array end positions.
    - Added Simulations/Ltspice/H_bridge.asc LTspice schematic for an H-bridge/motor drive.
    - Modified Software/Suntracker/src/Motors.h: adjusted MOTOR1_speed (100 -> 83) and MOTOR2_speed (400 -> 342) to reflect proportional speed reduction from 6V to 5V, reduced speed_start from 120 to 100, and preserved existing gearbox/servo constants. Minor formatting tweaks.
    [Motors.h]
2026-10-10 Create BOM
2026-10-19 Add concept hardware assembly and parts
    Add the Main assembly and three part files, ignore V2 OldVersions directories, and remove two temporary files.
2026-11-01 Update hardware and add model parameters
    Add the model parameter XML and update the base part. Remove the main assembly and obsolete bearing components.
2026-11-01 Add photoresistor mounts to hardware assembly
    Add the main assembly and LDR part, update the base model, and revise parameters for its dimensions, bearing count, mounting holes, and photoresistor layout.
2026-11-04 Add bearing and linkage CAD components
    Add two bearing models and new support, linkage, locomotive, and panel parts. Update the main assembly and existing screw and top parts.
    The linking mechanism still requires dimensional adjustments.
2026-11-05 Update V2 hardware CAD assembly
    Revise the main assembly and several part models, add the Shaft_drive part, and fit solar panel onto top part.
2026-11-07 Add gearbox pulleys and update hardware models
    Add pulley parts and assemblies, base parameter data, and updates to the main assembly and related hardware models.
2026-11-07 Add azimuth drive gearbox components
    Add the azimuth drive and gearbox parts, and update the main assembly, stepper motor, pulley, and top components.
2026-11-11 Added second PCB
